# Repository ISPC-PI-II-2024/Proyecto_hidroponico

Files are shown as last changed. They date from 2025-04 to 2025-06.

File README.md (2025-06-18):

# Proyecto_hidroponico

<p align="center">
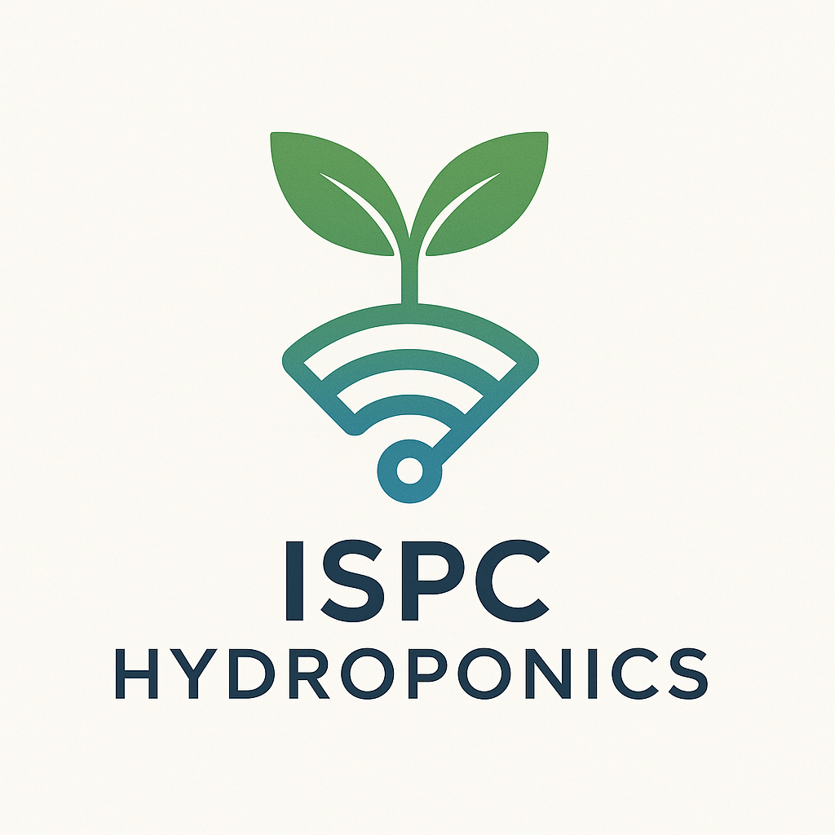
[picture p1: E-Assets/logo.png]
ISPC Hydroponics logo
  
</p>

<h1 align="center">ISPC Hydroponics</h1>

<p align="center">
  🌱 Cultivando el futuro con tecnología inteligente 💧
</p>

---

### 📌 DESCRIPCIÓN

**ISPC Hydroponics**: Este proyecto  propone el desarrollo de un sistema inteligente basado en IoT para monitorear y  automatizar variables clave en un cultivo hidropónico. Se implementa durante el primer cuatrimestre de 2024, empleando sensores, microcontroladores, protocolos  de comunicación y plataformas de visualización de datos. 
  
Es un proyecto tecnológico. Combina el diseño y programación de sistemas embebidos,  modelado de bases de datos y visualización con una investigación sobre las necesidades del cultivo hidropónico y su automatización. 

### 📌 PROBLEMÁTICA

La agricultura urbana enfrenta limitaciones en el acceso a tierra fértil y agua. Los cultivos hidropónicos requieren un control preciso de variables como pH, TDS, luz y temperatura. Se detecta la necesidad de automatizar y visualizar estos parámetros para asegurar la eficiencia del cultivo en contextos urbanos, educativos o de baja escala.

---

### 🧑‍💻 INTEGRANTES

| Nombre | GitHub |
|---|---|
| Romina Vanesa Huk | [@RoHu17](https://github.com/RoHu17) |
| Emma Vilma Gutierrez | [@emygut](https://github.com/emygut) |
| Macarena Aylèn Carballo | [@MacarenaAC](https://github.com/MacarenaAC) |
| Jose Luis Marquez | [@marquezjose](https://github.com/marquezjose) |
| Fernando Gimenez Coria | [@FerCbr](https://github.com/FerCbr) |
| Nahuel Lucas Velez | [@Lucasmurua19](https://github.com/Lucasmurua19) |
| Juan Diego Gonzalez Antoniazzi | [@JDGA1997](https://github.com/JDGA1997) |
| Lisandro Juncos Varalda | [@Lisandro-05](https://github.com/Lisandro-05) |
| Joaquin Emiliano Garzón | [@Joacogarzonn](https://github.com/Joacogarzonn) |
| Vittorio Durigutti | [@vittoriodurigutti](https://github.com/vittoriodurigutti) |
| Leandro Roldan | [@pleroldan](https://github.com/pleroldan) |
| Luciano Lujan | [@lucianoilujan](https://github.com/lucianoilujan) |
| Tiziano Paez | [@tpaez](https://github.com/tpaez) |
| Raul Jara | [@r-j28](https://github.com/r-j28) |
| Joaquin Zalazar | [@breaakerr](https://github.com/breaakerr) |
| Diego Ares | [@diegote7](https://github.com/diegote7) |
| Paola Pantoja | [@PaolaaPantoja](https://github.com/PaolaaPantoja) |

---

### EJES TEMÁTICOS/RED DE CONCEPTOS:

- Internet de las Cosas (IoT).
- Sistemas embebidos y sensores ambientales.
- Protocolos de comunicación (MQTT).
- Bases de datos y almacenamiento en la nube.
- Visualización de datos (Grafana, Node-RED).

Se busca fortalecer la capacidad de integración de tecnologías en soluciones reales, así como la habilidad para diseñar sistemas conectados y sostenibles con impacto social. 

---

### FUNDAMENTACIÓN

El proyecto fue elegido por su aplicabilidad práctica, potencial de escalabilidad y su conexión directa con la sustentabilidad alimentaria. Permite aplicar conocimientos técnicos en una solución concreta y útil, que responde tanto al perfil profesional como a una problemática global: La producción de alimentos en espacios reducidos con uso eficiente de recursos. Su impacto puede ampliarse a instituciones educativas, espacios comunitarios o pequeños productores. 

---

### STACK TECNOLÓGICO

- ESP32 + Sensores físicos
- Node-RED
- MQTT (Broker privado)
- MariaDB | Heidi-Workbench 
- Grafana
- Portainer (Orquestación Docker)
- GitHub (Scrum / Kanban)
- FAST API - Python
- VsCode + PlatformIO

---

### 📂 Organización

```
📁 /A-Requisitos                  → los requisitos del proyecto  
📁 /B-Investigacion               → Archivos de investigacion, procedimientos, apuntes, datasheets
    ┣ 📂Documentación
    ┣ 📂Información Técnica
    ┃ ┗ 📂datasheets
    ┣ 📂Integracion ..
📁 /C-Prototipos                  → Prototipos, pruebas unitarios, integraciones, etc 
    ┣ 📂Backend-APP
    ┣ 📂base de datos
    ┣ 📂Integrado V2
    ┣ 📂modelos_3D_para_imprimir
    ┣ 📂Pruebas_Unitarias
📁 /D-Presentacion                → Documentacion de presentacion, videos, diapositivas, manuales de uso
📁 /E-assets                      → Imágenes, logo, multimedia  
📄 README.md                      → Este archivo  
📄 LICENSE                        → Licencia del proyecto
```

### 🚀 Objetivos

- Monitorear variables ambientales (pH, humedad, temperatura).
- Controlar actuadores mediante Node-RED.
- Visualizar datos históricos en Grafana.
- Almacenar información en MariaDB.
- Integrar toda la arquitectura en una red Docker.
- Desarrollar e implementar una API REST para el acceso programático a los datos.

### 📂 Estructura de documentación

| Sección | Descripción |
|---|---|
| [1 - Introducción](docs/1-introduccion.md) | Presentación del proyecto y objetivos |
| [2 - Instalación](docs/2-instalacion.md) | Guía paso a paso para levantar el entorno |
| [3 - Arquitectura](docs/3-arquitectura.md) | Diagrama general del sistema IoT |
| [4 - Node-RED](docs/4-node-red.md) | Flujos de automatización y ejemplos |
| [5 - Grafana](docs/5-grafana.md) | Dashboards de visualización |
| [6 - Base de datos](docs/6-bd-mariadb.md) | Esquema de la BD y acceso |
| [8 - API REST](docs/8-api.md) | Descripción y endpoints de la API |

### 🧑‍💻 Accesos a entorno

<p align="center">
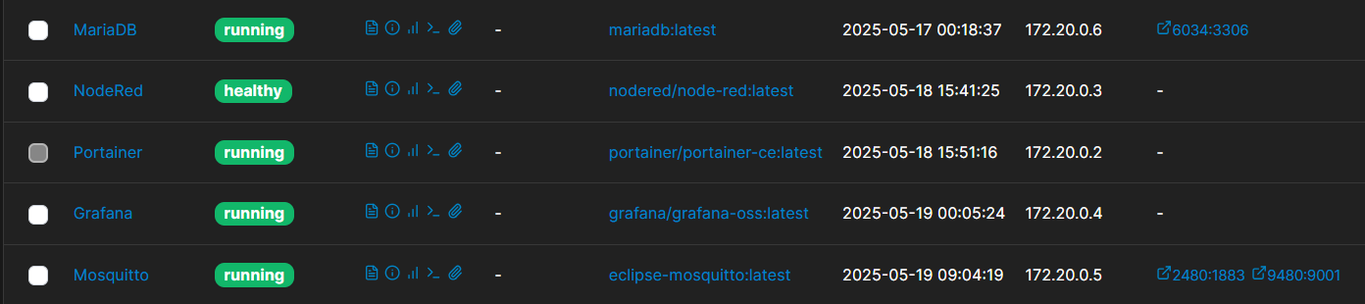
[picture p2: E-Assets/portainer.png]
Portainer logo
  
</p>

- [Node-RED](http://telecomunicaciones.ddns.net:8080/nodered/)
- [Dashboard UI](http://telecomunicaciones.ddns.net:8080/nodered/ui)
- [Grafana](http://telecomunicaciones.ddns.net:8080/grafana/)
- [Portainer](http://telecomunicaciones.ddns.net:8080/portainer/)
- [MariaDB](http://telecomunicaciones.ddns.net:6034)

> Usuario: `telecomunicaciones`  
> Contraseña: `cohorte*2024`

---

# 📘 1 - Introducción

El presente proyecto tiene como finalidad diseñar e implementar un sistema IoT para el monitoreo y control de un cultivo hidropónico. El enfoque está basado en el Aprendizaje Basado en Proyectos (ABP) integrando conocimientos adquiridos en las distintas materias del módulo FULLSTACK, correspondiente al segundo año de la tecnicatura en telecomunicaciones.

### 🧠 Justificación

- Automatización de cultivos.
- Acceso remoto a los datos.
- Toma de decisiones basada en analítica.

### 🎯 Objetivos

- Recolectar datos ambientales (humedad, pH, temperatura).
- Recolectar datos internos del sistema.
- Visualizar y analizar datos con dashboards.
- Aplicar control remoto mediante reglas automáticas, o interaccion remota y manual.
- Documentar el desarrollo siguiendo buenas prácticas de software.

---

### ⚙️ 2 - Instalación del entorno

**📦 Requisitos previos**
- Docker Desktop o Docker Engine
- Git

**🔁 Clonar el repositorio**

git clone https://github.com/ISPC-PI-II-2024/Proyecto_hidroponico.git
cd Proyecto_hidroponico

---

### 📄 3 - Arquitectura

**🧭 3 - Arquitectura del sistema**

<p align="center">
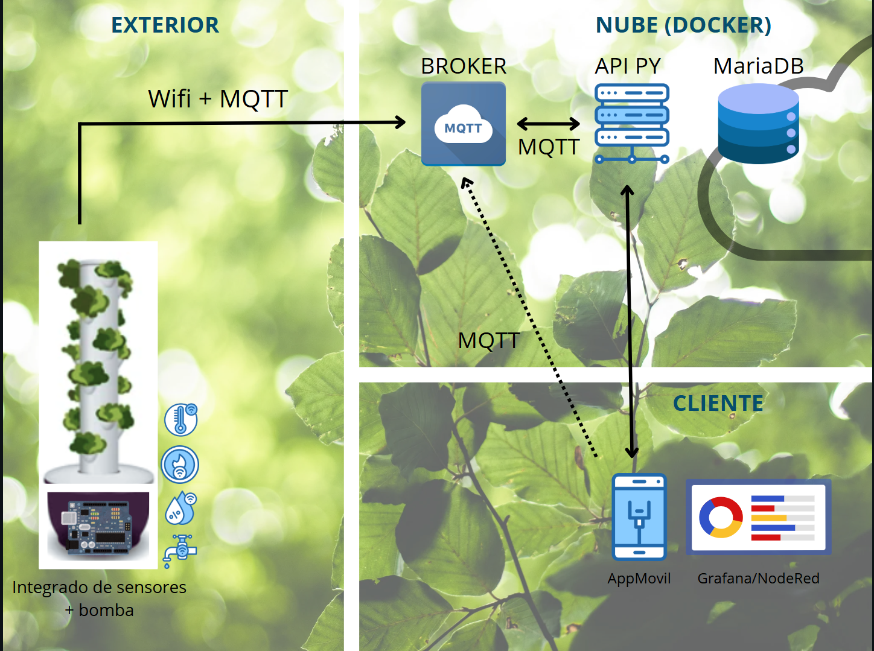
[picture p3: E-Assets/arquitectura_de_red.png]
ArquitecturaRed
  
</p>

**🔗 Descripción de componentes**

- **ESP32**: Captura datos de sensores.
- **Mosquitto**: Transmite los datos por MQTT.
- **Node-RED**: Procesa y enruta los datos.
- **MariaDB**: Almacena registros históricos.
- **Grafana**: Visualiza tendencias y análisis.

---

### 4 - Dispositivo Físico (Microcontrolador + Sistemas de sensores/actuadores)

Utilizando como cerebro del sistema un ESP32 que gestiona los sensores, actuadores y las conexiones, se disponen de un sistema extenso y complejo que nos permite leer variedad de valores del entorno, y de hasta dentro del sistema.

El mismo dispone de conexion via Wi-Fi, enviando lecturas, estado del sistemas y alarmas mediente MQTT. Toda la informacion es enviada via 2 tópicos:
- **dispositivo/info:** Este se utiliza solo al inicio/reincio del dispositivo. Está enmarcado solo dentro del setup, envía hacia la base de datos, vía broker + API el estado actual del dispositivo, indicando sensores, actuadores, las clases y los pines a los que conecta cada uno. Es sobre esta base de información, que luego se registrará cada lectura.
- **dispositivo/datos:** Este corresponde a un payload donde se envía la lectura de cada sensor, y el estado de cada actuador. El envío está programado cada 5s. Por lo que la visualización es prácticamente a tiempo real.

**Pruebas Unitarias**

- [Directorio de Pruebas unitarias](.//C-prototipos/Pruebas_Unitarias/)

A lo largo del proyecto se realizaron pruebas de cada elemento que compone el sistema, en un formato de clases, instanciado y modulado, lo cual facilitó su integración.

**Integraciones**
- [Integración: Version-1](.//C-prototipos/Integrado%20V1/)
- [Integración: Version-2](.//C-prototipos/Intregado%20V2/)

Dos formatos de integración fueron realizados. Siedo la versión 2 la que se encuentra efectivamente desplegada, y enviando datos al resto del sistema.

Dentro del directorio [Integración: Version-2] puede encontrarse información detallada del sistema, flujo de trabajo, componentes, configuración de cada elemento y manual de usuario para el menú y la interacción para con el sistema.

**Flujo de Trabajo**
```mermaid
flowchart TD
    %% Inicialización
    A[Inicio del Sistema] --> B[Inicializar Pantalla]
    B --> C[Inicializar WiFi]
    C --> D{WiFi OK?}
    D -- No --> C
    D -- Sí --> E[Conectar a MQTT Broker]
    E --> F{MQTT OK?}
    F -- No --> G[Back-off + Reintento MQTT]
    G --> E
    F -- Sí --> H[Inicializar Sensores]
    H --> I[Inicializar RTC]
    I --> J[Inicializar EEPROM]
    J --> K[Inicializar Módem GSM]
    K --> L[Entrar en Bucle Principal]
    
    %% Bucle Principal
    subgraph Bucle_Principal
      L --> M[Esperar intervaloLectura]
      M --> N[Leer Sensores]
      N --> O{mqttConectado?}
      O -- Sí --> P[Enviar datos vía MQTT]
      O -- No --> Q[Enviar datos vía GSM]
      P --> R[Actualizar Dashboard]
      Q --> R
      R --> S[Mostrar Menú/UI]
      S --> T{Interacción en Menú?}
      T -- Sí --> U[Procesar Comando Usuario]
      T -- No --> V[Continuar Bucle]
      U --> R
      V --> M
    end
```
---

## 📊 5A - Visualización con Grafana

Grafana permite construir dashboards con paneles que muestran en tiempo real o históricamente los datos del sistema hidropónico.

**🧩 Paneles incluidos**
- Temperatura del ambiente.
- Humedad del sustrato.
- Niveles de pH.
- Estado de los actuadores.
- Niveles generales de lectura de cada sensor.

**🔄 Fuentes de datos**
- MariaDB integrada como data source.

**🌐 Acceso Público:**
[CLICK AQUI](http://telecomunicaciones.ddns.net:8080/grafana/public-dashboards/855dc3a2826f476db1800452849f3251)

<p align="center">
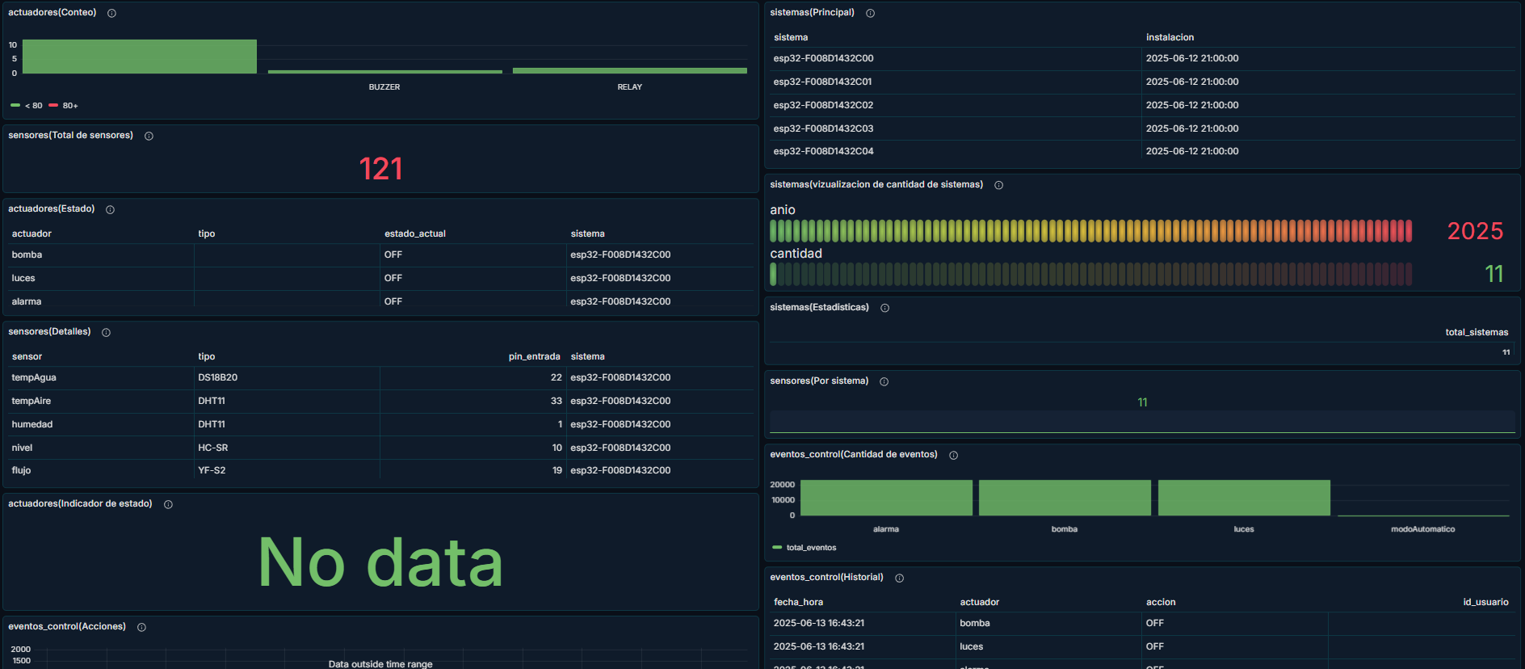
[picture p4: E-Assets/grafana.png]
Grafana
  
</p>

---

## 📊  5B - Automatización con Node-RED

Node-RED permite crear flujos lógicos para procesar, transformar y reenviar datos provenientes de sensores conectados vía MQTT.

**🔧 Funcionalidades implementadas**

- Recepción de datos desde ESP32 por MQTT.
- Filtrado y reenvío de datos a MariaDB.
- Reglas de control automático (p. ej., encendido de bombas).

**🌐 Flujos visuales:** [CLICK AQUI:](http://telecomunicaciones.ddns.net:8080/nodered/ui/#!/0?socketid=3i5QtwPpwfv6I9fGAAAq)

<p align="center">
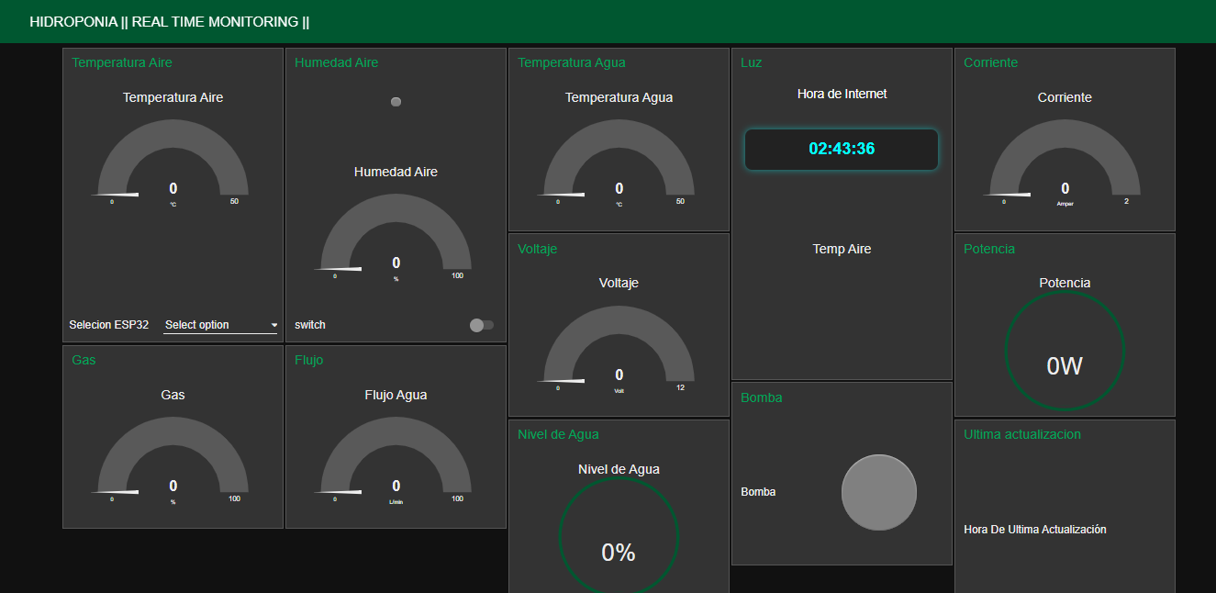
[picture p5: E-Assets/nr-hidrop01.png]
  
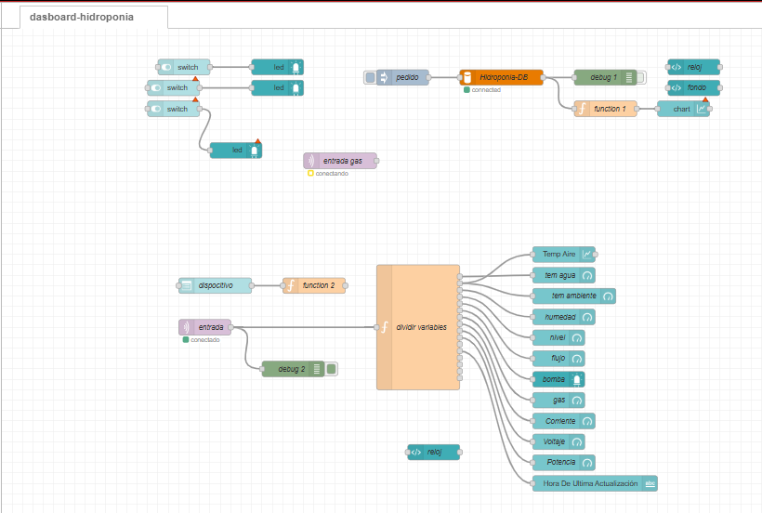
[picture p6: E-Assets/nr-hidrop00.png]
  
</p>

---
---

**🔐 Seguridad**

  #### **Los accesos a las consolas de configuracion de las aplicaciones de visualizacion como Node-RED y Grafana, montadas en el servidor privado, están protegidos con usuario y contraseña.**
  #### **Se reserva el uso solo a personal autorizado.**

---
---

## 🗃️ 6 - Base de datos MariaDB

MariaDB almacena los datos recolectados desde los sensores y enviados por Node-RED.

### 🧱 Estructura
1. **sistemas**
   - Representa cada instalación física del sistema hidropónico.
   - Un sistema puede tener múltiples sensores y actuadores.

2. **sensores**
   - Representa los sensores físicos instalados (ej: temperatura, humedad, pH).
   - Cada sensor está vinculado a un sistema y tiene un tipo, modelo, pin de entrada, etc.

3. **lecturas**
   - Almacena cada lectura generada por un sensor en una fecha y hora determinada.
   - Está directamente relacionada con un sensor.

4. **actuadores**
   - Representa los dispositivos controlables (bombas, luces, ventiladores, etc.).
   - Cada actuador está conectado a un sistema y tiene un estado actual (`ON` o `OFF`).

5. **eventos_control**
   - Registra los eventos donde un actuador fue activado o desactivado.
   - Puede incluir el nombre de la persona que realizó la acción (campo opcional `nombre_usuario`), aunque no se requiere autenticación.

6. **umbrales** 
   - Define los valores mínimos y máximos aceptables para ciertos tipos de sensores.
   - Permite generar alertas cuando una lectura está fuera de rango.

### 🔌 Conexión
- Host: `telecomunicaciones.ddns.net`
- Puerto: `6034`
- Usuario: `telecomunicaciones`
- Contraseña: `cohorte*2024`

Acceso a través de gestores como HeidiDB o MySQL Workbench, o mediante cualquier SGBD.

---

## 📡 7 - Broker MQTT (Privado, utilizando imagen de Mosquitto)

El broker MQTT se usa para recibir datos desde sensores IoT.

### 📍 Datos de conexión
- Broker: `mqtt://telecomunicaciones.ddns.net`
- Puerto: `2480` (MQTT) / `9480` (WebSocket)
- Usuario: `telecomunicaciones`
- Contraseña: `cohorte*2024`

### 📫 Topics utilizados
- `sensores/datos`
- `dispositivo/info`
- `hidroponico/control`

### 🧪 Pruebas
Podés usar MQTT Explorer para conectar y verificar los tópicos activos.
Se desarrollaron 3 aplicaciones simple que emulan datos, y envían información a los mismos tópicos a fin de afinar el parseo, registro y visualización de la información.
- [SimuladorCreacionDIspositivos.py](.//C-prototipos/Backend_APP/SimuladorCreacionDIspositivos.py)
- [SimuladorIngresoEspecifico.py](.//C-prototipos/Backend_APP/SimuladorIngresoEspecifico.py)
- [SimuladorLecturas.py](.//C-prototipos/Backend_APP/SimuladorLecturas.py)

--- 

## 🌐 8 - API REST

Se desarrolló una API tipo FastAPI, con cliente MQTT. 

### 📂 Ubicación en el repositorio
`/Backend_APP`

### 🧪 Endpoints principales
| Método | Endpoint | Descripción |
|---|---|---|
| GET | `/topic` | Obtener todas las segun el topico indicado/s en el .env |
| GET | `/message` | Obtener una lectura específica, segun el formato del mensaje |

### 🔐 Seguridad
Actualmente sin autenticación, se podrían añadir JWT o middleware de acceso en producción mas complejo o con alguna medida que sume a la seguridad.
Igualmente la API no tiene definido funciones para realizar consultas a la base de datos, únicamente para registrar cuando se cumple el formato correcto, en el topic específico.
Además, se encuentra resguardada, gracias a que el broker define para su conexion un usuario y contraseña, y un usuario de conexión creado en la DB que carece de perfil de administrador.

### 🧰 Tecnologías
- Cliente MQTT
- Docker-compose para su despliegue
- Body-parser con mapeo de datos
- Suscripción a múltiples dashboards
- Conexión a MariaDB, con healt check, y reconexión en caso de pérdida.

---

## 🌐 9 - DISEÑO 3D DE LOS MODULOS VERTICALES

Se diseñaron e imprimieron modulos utilizando tecnologia de impresion 3D, que mejorán la disposición de los actuadores, resguado del microcontrolador, y hasta disposición de las tuberías que facilitan el pase de cableado a lo lardo de la torre hidropónica.

**Diseñor y Desarrollo**
[modelos_3D_para_imprimir](.//C-prototipos/modelos_3D_para_imprimir/)

<p align="center">
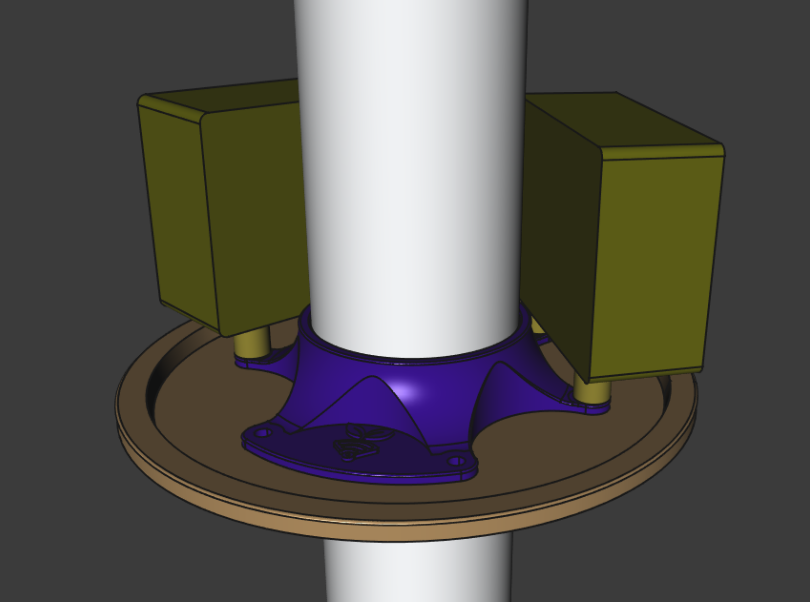
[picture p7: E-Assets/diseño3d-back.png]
Diseño 3D Back
  
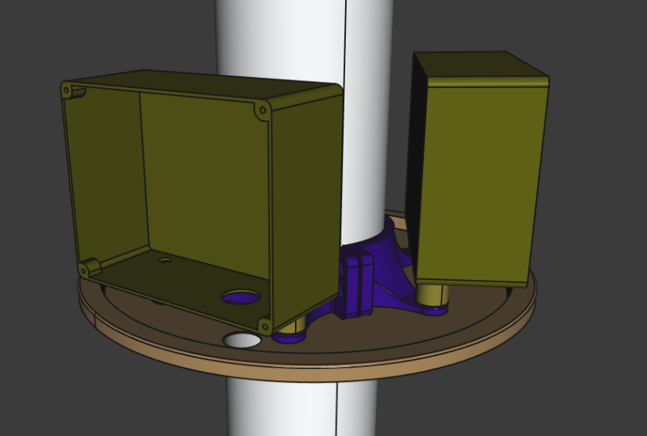
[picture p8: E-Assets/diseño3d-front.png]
Diseño 3D Front
  
</p>

---

### 📄 Licencia

Distribuido bajo la Licencia Creative Commons.

---

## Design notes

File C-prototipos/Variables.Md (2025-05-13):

# Proyecto Hidropónico: Variables y Base de Datos

Este sistema hidropónico estará integrado con **Node-RED** para la gestión de datos en tiempo real y **MariaDB** para el almacenamiento estructurado de información.
## Variables de Sensores y Control

- **`float temperaturaAgua`** → Registra la temperatura del agua en grados Celsius.
- **`float temperaturaAire`** → Mide la temperatura ambiental.
- **`float humedadAire`** → Indica la humedad relativa en el ambiente.
- **`float nivelAgua`** → Monitorea el nivel del agua en el sistema.
- **`float flujoAgua`** → Indica la velocidad de circulación del agua.
- **`int luz`** → Registra la cantidad de luz recibida por las plantas.
- **`int gas`** → Indica la concentración de gases en el ambiente.
- **`float corriente`**, **`float voltaje`**, **`float potencia`** → Variables eléctricas para el monitoreo energético.
- **`float ph`** → Mide el pH del agua para garantizar la absorción óptima de nutrientes.
- **`int lluvia`** → Indica si ha habido precipitaciones externas.
- **`int bomba`** → Estado de activación de la bomba de circulación.

## Variables de RTC (Real-Time Clock)

Para el registro preciso de datos en **MariaDB**, se incorporan variables de RTC:

- **`int año`** → Año actual.
- **`int mes`** → Mes actual.
- **`int día`** → Día actual.
- **`int hora`** → Hora actual.
- **`int minuto`** → Minuto actual.
- **`int segundo`** → Segundo actual.

## Estructura de la Base de Datos en MariaDB

### Creación de la Base de Datos y Tabla

```
CREATE DATABASE Hidroponico;
USE Hidroponico;

CREATE TABLE Sensores (
    id INT AUTO_INCREMENT PRIMARY KEY,
    temperaturaAgua FLOAT,
    temperaturaAire FLOAT,
    humedadAire FLOAT,
    nivelAgua FLOAT,
    flujoAgua FLOAT,
    luz INT,
    gas INT,
    corriente FLOAT,
    voltaje FLOAT,
    potencia FLOAT,
    ph FLOAT,
    lluvia INT,
    bomba INT,
    año INT,
    mes INT,
    día INT,
    hora INT,
    minuto INT,
    segundo INT,
    fecha_registro TIMESTAMP DEFAULT CURRENT_TIMESTAMP
);

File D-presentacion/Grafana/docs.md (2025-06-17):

# 📊 5 - Visualización con Grafana

Grafana es la herramienta utilizada para visualizar los datos recolectados por los sensores del sistema hidropónico. A través de paneles dinámicos, permite monitorear variables críticas como temperatura, humedad, y pH, facilitando el análisis y la toma de decisiones.

---

## 🔌 Conexión con MariaDB

Grafana se integra directamente con la base de datos MariaDB, donde se almacenan las lecturas enviadas desde Node-RED.

### 🔐 Datos de conexión

- **Host:** `telecomunicaciones.ddns.net`
- **Puerto:** `6034`
- **Usuario:** `telecomunicaciones`
- **Contraseña:** `cohorte*2024`
- **Base de datos:** Nombre asignado en tu contenedor 

Configuración realizada desde:  
`Connections → Data Sources → Add new → MySQL (MariaDB)`

---

## 🧩 Paneles incluidos en el Dashboard "Hidroponia"

En el dashboard actual se visualizan:

- 🌡️ **Temperatura ambiente**
- 💧 **Humedad del sustrato**
- 🧪 **Nivel de pH**

Cada panel está basado en una consulta SQL hacia la tabla `lecturas`, filtrando por tipo de sensor.

---

## 🧠 Cómo editar y entender un panel

1. Accedé a: [Dashboard Hidroponia](http://telecomunicaciones.ddns.net:8080/grafana/public-dashboards/855dc3a2826f476db1800452849f3251)
2. En cada panel, hacé clic en los tres puntos (︙) > **Edit** --> **OPCION DISPONIBLE SOLO PARA ADMINISTRADORES DEL SISTEMA**
3. Verás:
   - La **consulta SQL** al backend MariaDB
   - Tipo de visualización (línea, gauge, tabla)
   - Filtros aplicados (`$__timeFilter(timestamp)`)

### 📝 Ejemplo de consulta para temperatura

```sql
SELECT
  UNIX_TIMESTAMP(timestamp) as time_sec,
  valor as value
FROM lecturas
WHERE tipo_sensor = 'temperatura'
  AND $__timeFilter(timestamp)
ORDER BY timestamp ASC

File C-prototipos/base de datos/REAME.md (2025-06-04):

# Proyecto Hidropónico - Base de Datos

Este proyecto contiene el diseño y estructura de una base de datos relacional para el sistema hidropónico inteligente. La base de datos permite registrar sensores, lecturas, actuadores, eventos de control y sistemas instalados, siendo compatible con una interfaz tipo **dashboard** como **Node-RED** o **Grafana** para el monitoreo y control en tiempo real.

---

## Estructura de la Base de Datos

### Tablas principales:

1. **sistemas**
   - Representa cada instalación física del sistema hidropónico.
   - Un sistema puede tener múltiples sensores y actuadores.

2. **sensores**
   - Representa los sensores físicos instalados (ej: temperatura, humedad, pH).
   - Cada sensor está vinculado a un sistema y tiene un tipo, modelo, pin de entrada, etc.

3. **lecturas**
   - Almacena cada lectura generada por un sensor en una fecha y hora determinada.
   - Está directamente relacionada con un sensor.

4. **actuadores**
   - Representa los dispositivos controlables (bombas, luces, ventiladores, etc.).
   - Cada actuador está conectado a un sistema y tiene un estado actual (`ON` o `OFF`).

5. **eventos_control**
   - Registra los eventos donde un actuador fue activado o desactivado.
   - Puede incluir el nombre de la persona que realizó la acción (campo opcional `nombre_usuario`), aunque no se requiere autenticación.

6. **umbrales** 
   - Define los valores mínimos y máximos aceptables para ciertos tipos de sensores.
   - Permite generar alertas cuando una lectura está fuera de rango.

---

## 🔗 Relaciones entre tablas

```plaintext
sistemas ───< sensores ───< lecturas
        └──< actuadores ───< eventos_control

## Su Relación

### 1. **Inicio del ciclo - Lecturas desde los sensores**

- Cada **sensor** está instalado en un sistema hidropónico y está registrado en la tabla `sensores`.
- Cuando un sensor mide un dato (ej: humedad, temperatura, pH), se genera una **lectura** que se guarda en la tabla `lecturas`, junto con la **fecha**, **hora** y el **valor medido**.

> Ejemplo: el sensor de humedad `H1` toma una lectura de 35% a las 10:00 AM. Esa lectura se guarda en `lecturas` con relación directa al sensor `H1`.

---

### 2. **Visualización de datos en el dashboard**

- El sistema (por ejemplo, Node-RED o Grafana) consulta las lecturas recientes de la tabla `lecturas` para mostrar gráficos y datos en tiempo real.
- Cada sensor tiene un `tipo` (temperatura, humedad, etc.), lo cual permite agrupar y visualizar los datos adecuadamente.

---

### 3. **Análisis de condiciones - Comparación con umbrales**

- Si existe un **umbral** definido para cierto tipo de sensor (en la tabla `umbrales`), el sistema compara la lectura actual con esos valores.
- Si el valor está fuera del rango definido, se genera una alerta o se activa una lógica de control automático.

> Ejemplo: si la temperatura supera los 35 °C y el umbral máximo es 30 °C, se activa automáticamente un ventilador.

---

### 4. **Activación de actuadores (control manual o automático)**

- El sistema puede activar un **actuador** (como una bomba, luz o ventilador), el cual está registrado en la tabla `actuadores`.
- Cada actuador tiene un campo `estado_actual` (`ON` o `OFF`).
- Cuando se activa o desactiva un actuador, se registra un **evento** en la tabla `eventos_control`, que incluye la fecha, hora y, opcionalmente, el `nombre_usuario` si fue proporcionado desde el dashboard.

> Ejemplo: la bomba `B1` se enciende a las 10:05 AM. El sistema actualiza `estado_actual = 'ON'` en la tabla `actuadores`, y guarda un registro en `eventos_control` indicando qué actuador fue activado, a qué hora, y por quién si se ingresó el nombre.

---

### 5. **Acceso libre para múltiples personas**

- Hasta 20 personas pueden operar el sistema desde los dashboards sin necesidad de registrarse ni autenticarse.
- El campo `nombre_usuario` en `eventos_control` es opcional y puede usarse para dejar un registro manual de quién realizó una acción.
- No existen restricciones de acceso a nivel de base de datos, por lo que todos los operadores tienen acceso completo.

> Ejemplo: cualquier persona del equipo puede encender o apagar un actuador desde Node-RED. Si desea dejar su nombre, puede ingresarlo desde la interfaz para que se registre en la base de datos.

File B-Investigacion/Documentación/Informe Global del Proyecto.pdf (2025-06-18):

Informe Global del Proyecto: Hidroponía Inteligente para ESP32

El proyecto Hidroponia Inteligente está desarrollado sobre un ESP32 y está orientado a monitorear y controlar un sistema hidropónico de forma remota e inteligente. La arquitectura es modular, lo que permite integrar múltiples sensores, gestionar la automatización y establecer comunicación de diversas formas (WiFi + MQTT, BLE Mesh y LoRa Mesh).

Características Principales

- Sensores y Medidas
- Sensores ambientales: Temperatura y humedad (DHT11).
- Sensor de agua: Temperatura (DS18B20), nivel (ultrasónico) y flujo (caudalímetro).
- Medición adicional: Sensor de pH (con conversión básica que se puede calibrar).
- Otro: Sensor de luz (LDR), sensor de gas (MQ7) y monitorización de corriente/voltaje (INA219).
- Control y Automatización
- Gestión de riego y control de bomba.
- Control de iluminación artificial mediante un relé.
- Verificación de alarmas y notificaciones vía MQTT.
- Automatización adaptativa a partir de umbrales configurables (definidos en el módulo de control).
- Comunicaciones y Redes
- WiFi y MQTT: El ESP32 se conecta a una red WiFi y publica datos en un broker MQTT.
- BLE Mesh: Operación en red de malla a corto alcance mediante BLE.
- LoRa Mesh: Comunicación a largas distancias en redes remotas.
- Modos de Operación: Se puede configurar el nodo en modo transmisor (envía datos) o receptor (procesa y ejecuta comandos recibidos).

- Interfaz Visual y Menús
- Uso de una pantalla TFT (con Adafruit_GFX y ST7735) para mostrar información, menús interactivos y animaciones (modo standby, alertas, etc.).
- Menús para la configuración general, selección de recetas de cultivo y de red WiFi.
- Recetas de Cultivo y Configuración
- Almacenamiento en EEPROM de recetas con parámetros óptimos para diferentes cultivos (p.ej. lechuga, tomate, albahaca).
- Parámetros ajustables y calibración fina a través de archivos de configuración.
- Sincronización Horaria (RTC)
- Integración de módulos RTC (DS1307/DS3231) para mantener la hora correcta, programar eventos y registrar datos con marca temporal.

Ventajas y Escalabilidad

- Modularidad: Cada funcionalidad se encuentra en su propio módulo, lo que facilita la ampliación o modificación sin afectar el sistema global.
- Flexibilidad: Los nodos se pueden configurar como transmisores o receptores, permitiendo distintas arquitecturas de red para distribuir las tareas.
- Robustez: Los diferentes canales de comunicación (WiFi, BLE, LoRa) y el almacenamiento local (EEPROM) garantizan persistencia y adaptabilidad a diversas condiciones de red y energía.
- Diseñado para ESP32: Aprovecha la capacidad de procesamiento, conectividad WiFi/BLE y las múltiples interfaces analógicas/digitales que posee este microcontrolador.

Informe por Carpeta del Proyecto

A continuación, se describe en detalle la estructura del proyecto y los archivos que encontrarás en cada carpeta, junto con una breve descripción de sus responsabilidades.

Raíz del Proyecto

- Hidroponia.ino

Es el archivo principal que integra todos los módulos. En él se define el ciclo de trabajo (`setup()` y `loop()`), donde se inicializan la pantalla, sensores, control, comunicaciones y menús, y se coordina la lectura y envío de datos periódicamente.

- Configuración.h

Contiene definiciones y constantes globales (p.ej. velocidad de comunicación, versión del firmware) que se usan en varias partes del proyecto.

- Configuración_avanzada.h

Se establecen parámetros finos de calibración y ajustes avanzados (por ejemplo, constantes de calibración para el sensor de pH o parámetros de referencia para otros sensores).

Carpeta src/sensores

- sensores.h / sensores.cpp

Funcionalidad común para la lectura y manejo de sensores:

- Inicializa y lee datos de DHT11, DS18B20, sensor ultrasónico, caudalímetro, LDR, MQ7 y INA219.
- Proporciona variables globales para almacenar los valores medidos (temperatura del agua, temperatura ambiente, nivel de agua, flujo, etc.).
- ph_sensor.h / ph_sensor.cpp

Específico para el sensor de pH:

- Se encarga de inicializar el sensor y realizar la conversión analógica a un valor de pH, utilizando una fórmula básica que puede ser ajustada posteriormente.

Carpeta src/control

- control.h / control.cpp

Define la lógica de control:

- Establece umbrales para activar la bomba, gestionar riego y otros dispositivos.
- Incluye funciones para verificar alarmas basadas en las lecturas de los sensores y notificar eventos especiales (por ejemplo, baja del nivel de agua o pH fuera de rango).
- iluminacion.h / iluminacion.cpp

Maneja el control de un relé destinado a la iluminación artificial:

- Se definen funciones para inicializar el relé y cambiar su estado (encendido/apagado) dependiendo de las condiciones ambientales o configuraciones manuales.

Carpeta src/pantalla

- pantalla.h / pantalla.cpp

Encargado de la interfaz visual:

- Inicializa la pantalla TFT y define funciones para actualizarla, mostrar animaciones (modo standby o alertas) y renderizar información en pantalla.
- menu.h / menu.cpp

Proporciona el menú principal del sistema:

- Maneja la navegación del usuario para acceder a distintos apartados (sensores, control, recetas y configuración WiFi).
- menu_recetas.h / menu_recetas.cpp

Gestión del menú de recetas de cultivo:

- Permite la visualización, selección y edición de recetas almacenadas en EEPROM para ajustar parámetros de cultivo.

- menu_wifi.h / menu_wifi.cpp

Funcionalidades para la selección de red WiFi:

- Escanea las redes disponibles, muestra una lista en la pantalla y permite al usuario seleccionar la red a la que conectar el ESP32.

Carpeta src/comunicación

- comunicacion.h / comunicacion.cpp

Módulo central para la gestión de comunicaciones:

- Integra funciones para conectarse a WiFi, a un broker MQTT y para manejar la publicación y suscripción de mensajes.
- wifi_manager.h / wifi_manager.cpp

Gestión de las conexiones WiFi:

- Escanea redes WiFi, conecta al canal seleccionado y guarda los datos en EEPROM para la reconexión automática.
- ble_mesh.h / ble_mesh.cpp

Módulo para la comunicación mediante BLE Mesh:

- Configura un servidor BLE en el ESP32, define servicios y características para transmitir mensajes por Bluetooth en una red de malla.
- lora_mesh.h / lora_mesh.cpp

Módulo para la comunicación a larga distancia vía LoRa:

- Configura el módulo LoRa (por ejemplo, SX1278) con los pines y frecuencia adecuados, y gestiona el envío y recepción de mensajes.
- transmisor.h / transmisor.cpp

Define el modo transmisor:

- Recopila datos de los sensores y los envía (por ejemplo, vía MQTT). Se habilita o deshabilita mediante una variable (esNodoTransmisor).
- receptor.h / receptor.cpp

Define el modo receptor:

- Procesa los mensajes recibidos (por ejemplo, comandos para activar iluminación o ajustar parámetros) y ejecuta acciones en consecuencia.

Carpeta src/rtc

- rtc.h / rtc.cpp

Módulo para la gestión del reloj real (RTC):

- Inicializa el RTC, obtiene la fecha y hora actual y permite sincronizar el reloj (por ejemplo, mediante mensajes recibidos por MQTT).

Carpeta src/recetas

- recetas.h / recetas.cpp

Gestión de recetas de cultivo:

- Define la estructura `Receta` que almacena parámetros como temperatura, humedad, nivel de agua, pH e iluminación.
- Permite cargar y guardar estas recetas en EEPROM, seleccionar una receta y mostrar sus parámetros en el sistema.

Carpeta bibliotecas

- Librerías Externas

Esta carpeta se utiliza para almacenar (o referenciar) las librerías externas requeridas, tales como:

- Adafruit_GFX, Adafruit_ST7735 (para la pantalla TFT).

- PubSubClient (para MQTT).
- LoRa, BLEDevice, RTClib y EEPROM (incluida en Arduino).

La mayoría de estas librerías se instalan a través del gestor de librerías de Arduino o PlatformIO.

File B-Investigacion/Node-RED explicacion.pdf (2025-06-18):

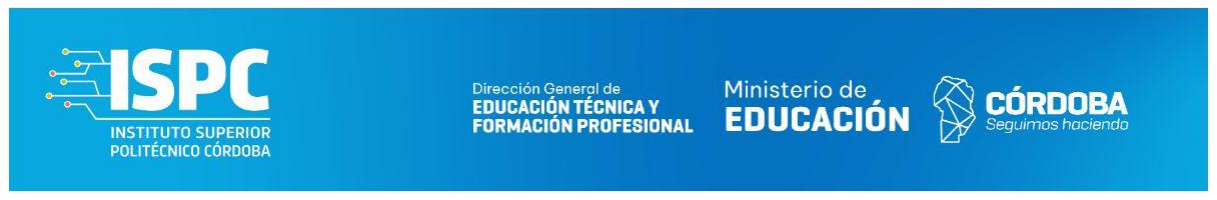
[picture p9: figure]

## NODE-RED

Node-RED es una herramienta de programación visual, de código abierto, creada para conectar dispositivos, APIs y servicios en línea de forma sencilla. Es especialmente útil para proyectos de Internet de las Cosas (IoT) y automatización, permitiendo conectar y controlar dispositivos de hardware, servicios en la nube y APIs mediante una interfaz gráfica basada en navegador.
En esencia, Node-RED permite construir aplicaciones arrastrando y conectando "nodos" que representan funciones, entradas o salidas. Estos nodos se conectan entre sí para crear flujos de trabajo que automatizan tareas, procesan datos y controlan dispositivos.

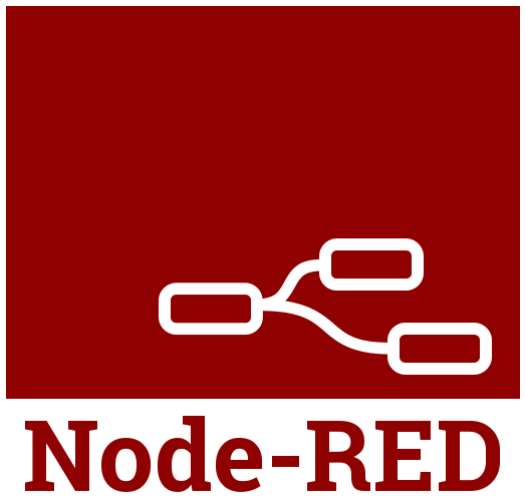
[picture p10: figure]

Características principales:
- Programación visual:
Facilita la creación de aplicaciones mediante la conexión visual de nodos, sin necesidad de escribir código complejo.
- Nodos:
Cada nodo realiza una función específica, como leer datos de un sensor, enviar un correo electrónico o controlar un actuador.
- Flujos:
Los nodos se conectan para formar flujos, que representan la secuencia de operaciones de la aplicación.

- Amplia gama de nodos:
Node-RED cuenta con una extensa librería de nodos para conectar dispositivos, servicios y APIs.
- Fácil de usar:
Es una herramienta intuitiva que permite a usuarios con diferentes niveles de experiencia construir aplicaciones.
- Código abierto:
Node-RED es gratuito y de código abierto, lo que permite su uso y adaptación a las necesidades de cada proyecto.
- Ejemplos de uso:
- Automatización del hogar: Controlar luces, termostatos y otros dispositivos inteligentes.
- Monitorización de datos: Recopilar y visualizar datos de sensores, como temperatura, humedad o consumo de energía.
- Conexión de dispositivos IoT: Integrar dispositivos como Raspberry Pi, Arduino y otros sensores en un sistema centralizado.
- Automatización industrial: Controlar maquinaria, monitorear procesos y analizar datos en tiempo real.
- Integración con servicios en la nube: Conectar con servicios como Dropbox, Google Drive, Amazon AWS y otros.
En resumen, Node-RED es una herramienta poderosa y versátil para la construcción de aplicaciones basadas en eventos, especialmente en el ámbito del IoT y la automatización, gracias a su interfaz visual, su amplia gama de nodos y su facilidad de uso.

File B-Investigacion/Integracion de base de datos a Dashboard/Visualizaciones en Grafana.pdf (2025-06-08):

# Visualizaciones en Grafana para el Sistema Hidropónia

Este documento explica la razón y utilidad de cada visualización implementada en Grafana para el monitoreo y control de sistemas hidropónicos. Cada tabla y panel está diseñado para aportar información clara y útil sobre diferentes aspectos del sistema, facilitando el análisis y la toma de decisiones.

## 1. Tabla: Sistemas

Visualización

- Panel Table

Que se puede ver?

Lista con todos los sistemas instalados, mostrando nombre y fecha de instalación.

Propósito

Permite identificar y referenciar los distintos sistemas hidropónicos registrados en la base de datos.

Uso en presentación

“Esta tabla nos da un panorama general de qué sistemas están activos y desde cuándo, lo cual es útil para tener contexto antes de analizar sensores o datos.”

## 2. Tabla: Sensores

Visualizaciones

- Panel Table: muestra nombre, tipo, pin de entrada y sistema asociado de cada sensor.
- Panel Bar chart: muestra el número de sensores por tipo (temperatura, humedad, etc.).
- Panel Bar chart o Pie chart: cantidad de sensores por sistema.

Propósito

Brinda un entendimiento completo sobre qué sensores están instalados, cómo se distribuyen por tipo y a qué sistema pertenecen.

Uso en presentación

“Con estas visualizaciones, podemos entender qué sensores hay, su distribución por tipo, y cómo están organizados en cada sistema. Esto es clave para interpretar las lecturas posteriores.”

## 3. Tabla: Lecturas

Visualizaciones

- Panel Time series: evolución temporal de los valores registrados por sensores.
- Panel Stat: muestra el valor más reciente (última lectura) de un sensor.
- Panel Table: lecturas recientes ordenadas cronológicamente.

Propósito

Monitorear los datos en tiempo real y analizar tendencias o cambios en las variables ambientales.

Uso en presentación

“Aquí vemos cómo varían las mediciones en tiempo real, lo cual nos ayuda a monitorear el estado del sistema. También mostramos la última lectura y un resumen general.”

## 4. Tabla: Actuadores

Visualizaciones

- Panel Table: lista de actuadores con tipo, estado actual, pines y sistema asociado.
- Panel Stat o Gauge: número total de actuadores activos (estado ON).
- Panel Pie chart: distribución de actuadores por tipo (bombas, luces, ventiladores, etc.).

Propósito

Permitir el control y monitoreo del estado de los dispositivos que actúan sobre el sistema.

Uso en presentación

“Aquí controlamos el estado actual de los dispositivos que actúan sobre el sistema. Podemos ver cuántos están activos y cómo están distribuidos.”

## 5. Tabla: Eventos de Control

Visualizaciones

- Panel Table: registro detallado de eventos (qué actuador fue activado/desactivado, cuándo y por qué usuario).
- Panel Bar chart: cantidad de acciones por tipo (ON/OFF).
- Panel Time series: frecuencia de eventos a lo largo del tiempo.

Propósito

Ofrecer un historial de acciones para auditoría y análisis del uso de actuadores.

Uso en presentación

“Esta tabla actúa como un historial de acciones. Nos ayuda a auditar quién activó qué actuador y con qué frecuencia.”

## 6. Tabla: Umbrales

Visualizaciones

- Panel Table: valores mínimos y máximos configurados para cada tipo de sensor.
- Panel Time series combinado con lecturas: muestra lecturas reales junto a bandas de umbral para detectar valores fuera de rango.
- Panel Stat o Bar chart: cantidad de veces que un sensor superó los umbrales establecidos.

Propósito

Detectar condiciones críticas o fallas cuando un sensor registra valores fuera del rango esperado.

Uso en presentación

“Esto permite visualizar cuándo un sensor está funcionando fuera de lo esperado. Es crucial para detectar fallos o condiciones críticas en el sistema.”

Cada visualización fue diseñada para facilitar el monitoreo, análisis y control efectivo de los sistemas hidropónicos. Juntas, proporcionan una visión integral y clara del estado actual, el historial y el desempeño general, apoyando la toma de decisiones informadas.

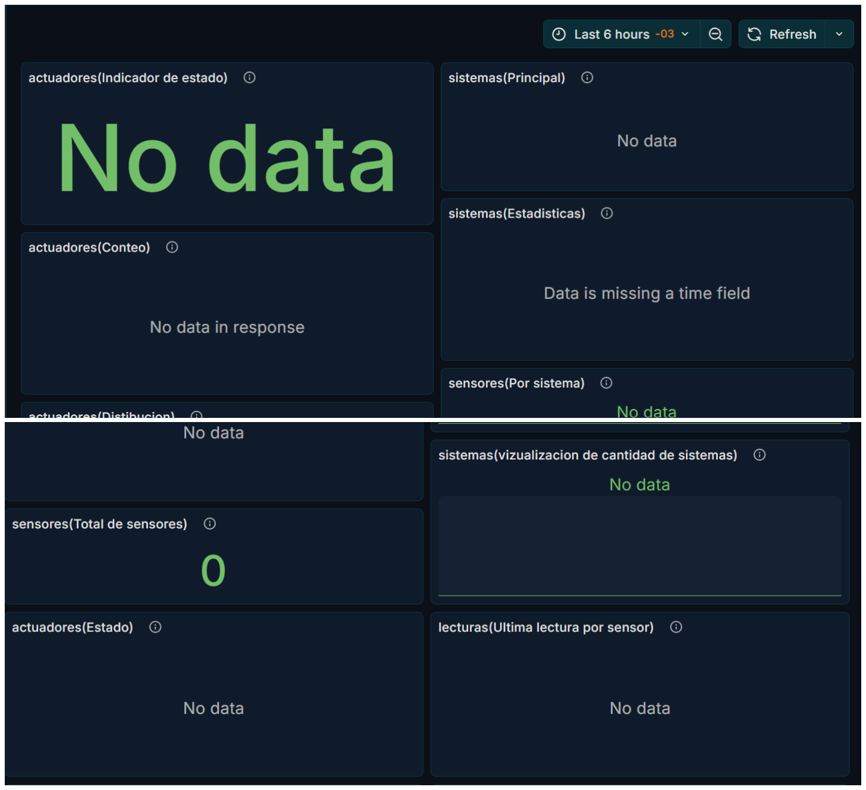
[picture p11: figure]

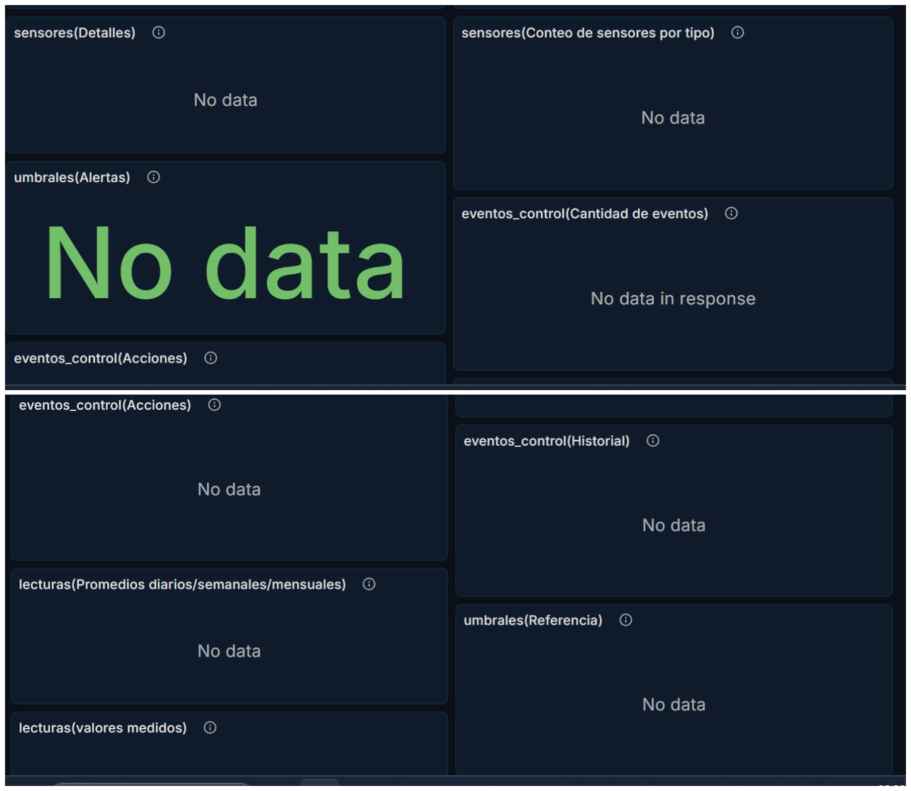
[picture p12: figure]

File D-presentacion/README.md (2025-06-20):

# Proyecto_hidroponico

<p align="center">
  ISPC Hydroponics logo
</p>

<h1 align="center">ISPC Hydroponics</h1>

<p align="center">
  🌱 Cultivando el futuro con tecnología inteligente 💧
</p>

---

## 📌 Descripción

**ISPC Hydroponics** es un proyecto IoT colaborativo desarrollado por estudiantes del Instituto Superior Politecnico Cordoba, correspondientes a la materia Proyecto Integrador 2 de la Tecnicatura Superior en Telecomunicaciones.
En el mismo se busca aplicar tecnología para monitorear y automatizar un sistema de cultivo hidropónico. 
El objetivo es construir una solución inteligente, ecológica y accesible que combine sensores, microcontroladores y visualización en tiempo real.

---

## 🧑‍💻 Integrantes

| Nombre | GitHub |
|---|---|
| Romina Vanesa Huk | [@RoHu17](https://github.com/RoHu17) |
| Emma Vilma Gutierrez | [@emygut](https://github.com/emygut) |
| Macarena Aylèn Carballo | [@MacarenaAC](https://github.com/MacarenaAC) |
| Jose Luis Marquez | [@marquezjose](https://github.com/marquezjose) |
| Fernando Gimenez Coria | [@FerCbr](https://github.com/FerCbr) |
| Nahuel Lucas Velez | [@Lucasmurua19](https://github.com/Lucasmurua19) |
| Juan Diego Gonzalez Antoniazzi  | [@JDGA1997](https://github.com/JDGA1997) |
| Lisandro Juncos Varalda | [@Lisandro-05](https://github.com/Lisandro-05) |
| Joaquin Emiliano Garzón | [@Joacogarzonn](https://github.com/Joacogarzonn) |
| Vittorio Durigutti | [@vittoriodurigutti](https://github.com/vittoriodurigutti)|
| Leandro Roldan | [@pleroldan](https://github.com/pleroldan) |
| Luciano Lujan | [@lucianoilujan](https://github.com/lucianoilujan) |
| Tiziano Paez | [@tpaez](https://github.com/tpaez) |
| Raul Jara | [@r-j28](https://github.com/r-j28) | 
| Joaquin Zalazar | [@breaakerr](https://github.com/breaakerr) |
| Diego Ares | [@diegote7](https://github.com/diegote7) |
| Paola Pantoja | [@PaolaaPantoja](https://github.com/PaolaaPantoja) |

---

## 🚀 Tecnologías

- ESP32
- Sensores de pH, EC, temperatura, humedad, luz
- MQTT / HTTP
- Node-RED / Web dashboard
- Visualización en tiempo real

---

## 📂 Organización

```
📁 /Requisitos         → los requisitos del proyecto  
📁 /Investigacion      → Archivos de investigacion, procedimientos, apuntes, datasheets 
📁 /Prototipos         → Prototipos, pruebas unitarios, integraciones, etc 
📁 /Presentacion       → Documentacion de presentacion, videos, diapositivas, manuales de uso
📁 /assets       → Imágenes, logo, multimedia  
📄 README.md     → Este archivo  
📄 LICENSE       → Licencia del proyecto
```

---

## 📄 Licencia

Distribuido bajo la Licencia Creative Commons.

---

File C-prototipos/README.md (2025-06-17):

# Proyecto_hidroponico

<p align="center">
  ISPC Hydroponics logo
</p>

<h1 align="center">ISPC Hydroponics</h1>

<p align="center">
  🌱 Cultivando el futuro con tecnología inteligente 💧
</p>

---

## 📌 Descripción

**ISPC Hydroponics** es un proyecto IoT colaborativo desarrollado por estudiantes del Instituto Superior Politecnico Cordoba, correspondientes a la materia Proyecto Integrador 2 de la Tecnicatura Superior en Telecomunicaciones.
En el mismo se busca aplicar tecnología para monitorear y automatizar un sistema de cultivo hidropónico. 
El objetivo es construir una solución inteligente, ecológica y accesible que combine sensores, microcontroladores y visualización en tiempo real.

---

## 🧑‍💻 Integrantes

| Nombre | GitHub |
|---|---|
| Romina Vanesa Huk | [@RoHu17](https://github.com/RoHu17) |
| Emma Vilma Gutierrez | [@emygut](https://github.com/emygut) |
| Macarena Aylèn Carballo | [@MacarenaAC](https://github.com/MacarenaAC) |
| Jose Luis Marquez | [@marquezjose](https://github.com/marquezjose) |
| Fernando Gimenez Coria | [@FerCbr](https://github.com/FerCbr) |
| Nahuel Lucas Velez | [@Lucasmurua19](https://github.com/Lucasmurua19) |
| Juan Diego Gonzalez Antoniazzi | [@JDGA1997](https://github.com/JDGA1997) |
| Lisandro Juncos Varalda | [@Lisandro-05](https://github.com/Lisandro-05) |
| Joaquin Emiliano Garzón | [@Joacogarzonn](https://github.com/Joacogarzonn) |
| Vittorio Durigutti | [@vittoriodurigutti](https://github.com/vittoriodurigutti) |
| Leandro Roldan | [@pleroldan](https://github.com/pleroldan) |
| Luciano Lujan | [@lucianoilujan](https://github.com/lucianoilujan) |
| Tiziano Paez | [@tpaez](https://github.com/tpaez) |
| Raul Jara | [@r-j28](https://github.com/r-j28) |
| Joaquin Zalazar | [@breaakerr](https://github.com/breaakerr) |
| Diego Ares | [@diegote7](https://github.com/diegote7) |
| Paola Pantoja | [@PaolaaPantoja](https://github.com/PaolaaPantoja) |

---

## 🧰 Tecnologías usadas

- ESP32 + sensores físicos
- Node-RED
- MQTT (Mosquitto)
- MariaDB
- Grafana
- Portainer (orquestación Docker)
- GitHub (Scrum / Kanban)
- Power BI (análisis final)
- API REST en Node.js/Express
- Visualización en tiempo real

---

## 📂 Organización

```
📁 /Requisitos         → los requisitos del proyecto  
📁 /Investigacion      → Archivos de investigacion, procedimientos, apuntes, datasheets 
📁 /Prototipos         → Prototipos, pruebas unitarios, integraciones, etc 
📁 /Presentacion       → Documentacion de presentacion, videos, diapositivas, manuales de uso
📁 /assets       → Imágenes, logo, multimedia  
📄 README.md     → Este archivo  
📄 LICENSE       → Licencia del proyecto
```

## 🚀 Objetivos

- Monitorear variables ambientales (pH, humedad, temperatura).
- Controlar actuadores mediante Node-RED.
- Visualizar datos históricos en Grafana.
- Almacenar información en MariaDB.
- Integrar toda la arquitectura en una red Docker.
- Desarrollar e implementar una API REST para el acceso programático a los datos.

## 🧰 Tecnologías usadas

## 📂 Estructura de documentación

| Sección | Descripción |
|---|---|
| [1 - Introducción](docs/1-introduccion.md) | Presentación del proyecto y objetivos |
| [2 - Instalación](docs/2-instalacion.md) | Guía paso a paso para levantar el entorno |
| [3 - Arquitectura](docs/3-arquitectura.md) | Diagrama general del sistema IoT |
| [4 - Node-RED](docs/4-node-red.md) | Flujos de automatización y ejemplos |
| [5 - Grafana](docs/5-grafana.md) | Dashboards de visualización |
| [6 - Base de datos](docs/6-bd-mariadb.md) | Esquema de la BD y acceso |
| [7 - MQTT Broker](docs/7-mqtt-broker.md) | Configuración y pruebas del broker MQTT |
| [8 - API REST](docs/8-api.md) | Descripción y endpoints de la API |

## 🧑‍💻 Accesos a entorno

- [Node-RED](http://telecomunicaciones.ddns.net:8080/nodered/)
- [Dashboard UI](http://telecomunicaciones.ddns.net:8080/nodered/ui)
- [Grafana](http://telecomunicaciones.ddns.net:8080/grafana/)
- [Portainer](http://telecomunicaciones.ddns.net:8080/portainer/)
- [MariaDB](http://telecomunicaciones.ddns.net:6034)

> Usuario: `telecomunicaciones`  
> Contraseña: `cohorte*2024`
---

# 📘 1 - Introducción

El presente proyecto tiene como finalidad diseñar e implementar un sistema IoT para el monitoreo y control de un cultivo hidropónico. El enfoque está basado en el Aprendizaje Basado en Proyectos (ABP) integrando conocimientos adquiridos en distintas materias técnicas de segundo año.

## 🧠 Justificación

- Automatización de cultivos.
- Acceso remoto a los datos.
- Toma de decisiones basada en analítica.

## 🎯 Objetivos

- Recolectar datos ambientales (humedad, pH, temperatura).
- Visualizar y analizar datos con dashboards.
- Aplicar control remoto mediante reglas automáticas.
- Documentar el desarrollo siguiendo buenas prácticas de software.
---

# ⚙️ 2 - Instalación del entorno

## 📦 Requisitos previos
- Docker Desktop o Docker Engine
- Git

## 🔁 Clonar el repositorio

git clone https://github.com/ISPC-PI-II-2024/Proyecto_hidroponico.git
cd Proyecto_hidroponico

### 📄 3 - Arquitectura

# 🧭 3 - Arquitectura del sistema

## 🌐 Diagrama general

## 🔗 Descripción de componentes

- **ESP32**: Captura datos de sensores.
- **Mosquitto**: Transmite los datos por MQTT.
- **Node-RED**: Procesa y enruta los datos.
- **MariaDB**: Almacena registros históricos.
- **Grafana**: Visualiza tendencias y análisis.
---

# 🔄 4 - Automatización con Node-RED

Node-RED permite crear flujos lógicos para procesar, transformar y reenviar datos provenientes de sensores conectados vía MQTT.

## 🔧 Funcionalidades implementadas

- Recepción de datos desde ESP32 por MQTT.
- Filtrado y reenvío de datos a MariaDB.
- Reglas de control automático (p. ej., encendido de bombas).

## 🌐 Flujos visuales

(Sugerencia: insertar aquí una imagen del flujo Node-RED o exportar como JSON y documentarlo)

## 🔐 Seguridad

El acceso a Node-RED está protegido con usuario y contraseña.
---

# 📊 5 - Visualización con Grafana

Grafana permite construir dashboards con paneles que muestran en tiempo real o históricamente los datos del sistema hidropónico.

## 🧩 Paneles incluidos
- Temperatura del ambiente.
- Humedad del sustrato.
- Niveles de pH.

## 🔄 Fuentes de datos
- MariaDB integrada como data source.

## 🌐 Acceso
http://telecomunicaciones.ddns.net:8080/grafana/

http://telecomunicaciones.ddns.net:8080/grafana/
---

# 🗃️ 6 - Base de datos MariaDB

MariaDB almacena los datos recolectados desde los sensores y enviados por Node-RED.

## 🧱 Estructura
- `lecturas` (id, tipo_sensor, valor, timestamp)
- `alertas` (id, tipo, descripcion, timestamp)

## 🔌 Conexión
- Host: `telecomunicaciones.ddns.net`
- Puerto: `6034`
- Usuario: `telecomunicaciones`
- Contraseña: `cohorte*2024`

Acceso a través de gestores como MariaDB o MySQL Workbench.
---

# 📡 7 - Broker MQTT (Mosquitto)

El broker MQTT se usa para recibir datos desde sensores IoT.

## 📍 Datos de conexión
- Broker: `mqtt://telecomunicaciones.ddns.net`
- Puerto: `2480` (MQTT) / `9480` (WebSocket)
- Usuario: `telecomunicaciones`
- Contraseña: `cohorte*2024`

## 📫 Topics utilizados
- `hidroponico/temperatura`
- `hidroponico/humedad`
- `hidroponico/ph`

## 🧪 Pruebas
Podés usar MQTT Explorer para conectar y verificar los tópicos activos.
--- 

# 🌐 8 - API REST

Se desarrolló una API RESTful en Node.js utilizando Express para acceder a los datos del sistema.

## 📂 Ubicación en el repositorio
`/api`

## 🧪 Endpoints principales
| Método | Endpoint | Descripción |
|---|---|---|
| GET | `/api/lecturas` | Obtener todas las lecturas |
| GET | `/api/lecturas/:id` | Obtener una lectura específica |
| POST | `/api/lecturas` | Agregar una nueva lectura |
| DELETE | `/api/lecturas/:id` | Eliminar una lectura |

## 🔐 Seguridad
Actualmente sin autenticación, se recomienda añadir JWT o middleware de acceso en producción.

## 🧰 Tecnologías
- Node.js
- Express
- Body-parser
- Conexión a MariaDB
---

## 📄 Licencia

Distribuido bajo la Licencia Creative Commons.

---

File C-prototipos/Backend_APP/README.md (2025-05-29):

## API 01

### Procesamiento de Informacion y Registro en BD

Esta API funcionara como el nodo conector entre el dispositivo fisico y las Bases de datos.
Purgara la informacion, y ordenara, y posteriormente registrara en los formatos adecuador para poder reflejar los datos de manera informativa, y en tiempo real. 
La misma escuchara de forma pasiva los mensajes presnetes en los topicos en que los dispositivos registren sus lecturas, corriendo en un contenedor Docker, conectado a la red donde se desplegaran asi mismo la base de datos en MariaDB

---

### Estructura del Directorio

- 📦Backend
-  ┣ 📂app                          // Directorio principal de la aplicacion
-  ┃ ┣ 📂api                        // Elementos de inico de la AIP y gestion de routas [host/api]
-  ┃ ┃ ┣ 📜routes.py                // Gestor de rutas definidas en la aplicacion
-  ┃ ┃ ┗ 📜__init__.py              // Elemento importador de los endpoind del directorio 
-  ┃ ┣ 📂models                     // Elementos asociado a modelos predefinidos, de momento solo estructura de los mensajes recividos
-  ┃ ┃ ┗ 📜mensaje.py               // Estructurador de formato de los mensjaes
-  ┃ ┣ 📂services                   // Estructura la conexion con los diferentes servicios a los que conecta la API
-  ┃ ┃ ┗ 📜maria_serv.py            // Estructura conexion con la base de datos en MySQL
-  ┃ ┣ 📂utils
-  ┃ ┃ ┗ 📜logger.py                // Gestiona los logs del sistema, asi como la categorizacion de los mismos
-  ┃ ┣ 📜config.py                  // Configuracion de la aplicacion y sus endpoints. Estps son llamados del .env
-  ┃ ┣ 📜main.py                    // Cuerpo de la aplicacion. Inicio, gestion del listener, del healtcheck, y ruta principal  
-  ┃ ┣ 📜mqtt_listener.py           // Listener en segundo plano de las conexiones y topicos MQTT
-  ┃ ┗ 📜__init__.py
-  ┣ 📜.env                         // Documento de enviroment donde se definen los valores finales antes de desplegar
-  ┣ 📜docker-compose.yml           // Docke-compose para creacion y parametros del contenedor
-  ┣ 📜Dockerfile
-  ┣ 📜README.md
-  ┗ 📜requirements.txt             // Librerias/instalaciones que deben ejecutarse en la imagen del contenedor

---

### Instacion solicitadas en el "requirements.txt"
- fastapi
    - Framework web asíncrono sobre el que montamos nuestros endpoints y el ciclo de vida de la app.
- uvicorn[standard]
    - Servidor ASGI ligero para ejecutar FastAPI, con extras ([standard]) como watchdog para recarga en caliente.
- paho-mqtt
    - Cliente MQTT para suscribirte a topics y procesar mensajes.
- mysql-connector-python
    - Driver oficial de Oracle para conectar a MySQL desde Python.
- python-dotenv
    - (Opcional si tu editor o entorno no carga .env automáticamente) permite que Pydantic BaseSettings lea tu .env.
- sqlalchemy
    - ORM/kit de conexión SQL que te facilitará abstraer consultas y gestión de sesiones en MySQL.

---

### Flujo de Datos

```mermaid
flowchart LR
  %% Dispositivo que envía mensajes al broker MQTT
  Dispositivo[Dispositivo]

  %% MQTT subsystem
  subgraph MQTT_Listener
    direction TB
    Broker[MQTT Broker]
    Listener["MQTTListener
(on_message)"]
  end

  %% Persistence services
  subgraph Persistence
    direction TB
    MySQLService[MySQL Service]
    MySQLDB[(MySQL DB)]
  end

  %% HTTP API
  subgraph HTTP_API
    direction TB
    Client["API Client
(e.g. dashboard)"]
    FastAPI[FastAPI App]
    Router[/api router/]
    Health[/GET /health/]
    Topics[/GET /api/topics/]
    Messages[/GET /api/messages/]
  end

  %% Connections
  Dispositivo --> Broker
  Broker --> Listener
  Listener -->|payload JSON| MySQLService
  MySQLService --> MySQLDB

  Client --> FastAPI
  FastAPI --> Health
  FastAPI --> Router
  Router --> Topics
  Router --> Messages
  Messages -->|consulta| MySQLService

```

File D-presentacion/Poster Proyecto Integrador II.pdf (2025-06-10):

Tecnológico

Proyecto IntegradorII

Internet de las Cosas (IoT).
Sistemas embebidos y sensores ambientales. Protocolos de comunicación (MQTT).
Bases de datos y almacenamiento en la nube. Visualización de datos (Grafana, Node-RED).
Se busca fortalecerla capacidad de integración de tecnologías en soluciones reales, así como la habilidad para diseñar sistemas conectados y sostenibles con impacto social.

La agricultura urbana enfrenta limitaciones en el acceso a tierra fértil y agua. Los cultivos hidropónicos requieren un control preciso de variables como pH, TDS, luz y temperatura. Se detecta la necesidad de automatizar y visualizar estos parámetros para asegurar la eficiencia del cultivo en contextos urbanos, educativos o de baja escala.

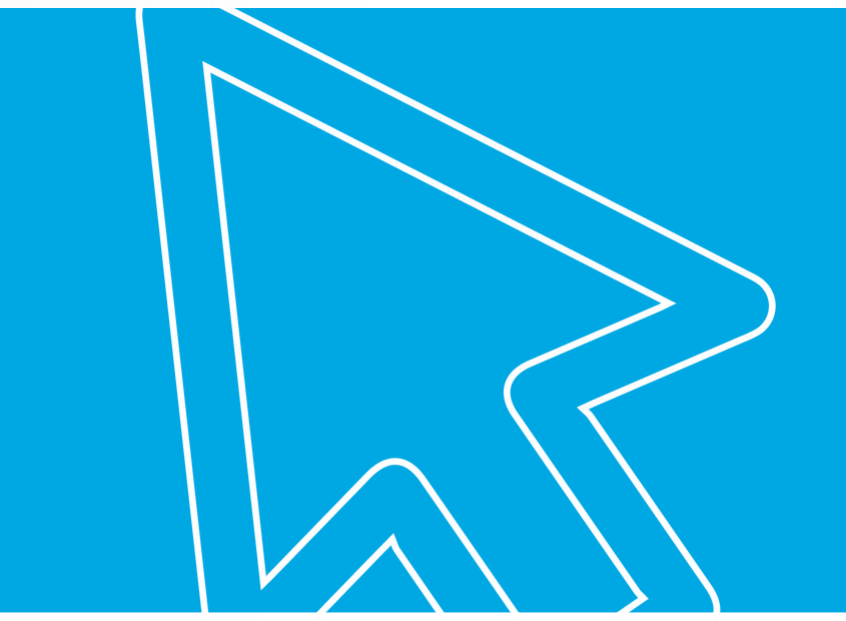
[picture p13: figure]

Desarrollar un sistema inteligente de monitoreo y automatización para cultivo hidropónico que permite controlar variables ambientales críticas y visualizar datos en tiempo real.

Integrar sensores de pH, TDS,temperatura, luz y caudal en una única plataforma. Establecer comunicación eficiente mediante MQTT y registrar datos en una base de datos relacional.
Crear dashboards funcionales en Grafana y Node-RED.
Automatizar el accionamiento de bombas y relés según umbrales definidos.

# ISPC HIDROPONICS

El proyecto fue elegido por su aplicabilidad práctica, potencial de escalabilidad y su conexión directa con la sustentabilidad alimentaria. Permite aplicar conocimientos técnicos en una solución concreta y útil, que responde tanto al perfil profesional como a una problemática global: la producción de alimentos en espacios reducidos con uso eficiente de recursos. Su impacto puede ampliarse a instituciones educativas, espacios comunitarios o pequeños productores.

TIPO DE PROYECTO:

ESPACIO CURRICULAR/MÓDULO:

EJE TEMÁTICO/RED DE CONCEPTOS:

PROBLEMÁTICAS/NECESIDADES:

FUNDAMENTACIÓN:

El producto final consiste en un sistema de cultivo hidropónico con monitoreo ambiental automatizado y visualización de datos en tiempo real. Este sistema integra sensores, microcontroladores, bases de datos y dashboards funcionales, y puede ser aplicado tanto en entornos educativos como comunitarios.
Además, se generará documentación técnica que puede compartirse con otras instituciones o en redes para difundir el valor de los cultivos hidropónicos inteligentes. Para más información ingrese al Repositorio Proyecto Hidropónico. https://github.com/ISPC-PI-II-2024/Proyecto_hidroponico.

PRODUCTO FINAL:

OBJETIVO GENERAL:

OBJETIVO ESPECÍFICO:

INTEGRANTES:
TECNICATURA:

COHORTE: DOCENTE:

Fernando Gimenez Coria
Diego Ares
Macarena Carballo
Lisandro Juncos
Vittorio Durigutti
Luciano Lujan
Jose Luis Marquez
Juan Diego Gonzalez Antoniazzi

Superior en Telecomunicaciones

2024 Mario Gonzalez

- Selección y prueba de sensores.
- Conexión física y validación individual.
- Codificación para lectura de datos.
- Configuración del broker MQTT.
- Programación de envío de datos.
- Creación y prueba de base de datos MySQL.
- Almacenamiento automático de lecturas. -Instalación de Grafana y Node-RED.
- Configuración de entradas desde base de datos.
- Diseño de paneles visuales para cada variable.
- Codificación de lógica de control.
- Conexión y prueba de relé y bomba.
- Implementación de condiciones automatizadas.

ACCIONES:

### Objetivo 1

### Objetivo 2

### Objetivo 3

### Objetivo 4

Joaquin Zalazar
Tiziano Paez
Leandro Roldan
Nahuel Velez
Paola Pantoja
Romina Huk
Emma Gutierrez
Raul Jara

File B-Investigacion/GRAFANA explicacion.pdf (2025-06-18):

## GRAFANA

Grafana es una plataforma de código abierto, principalmente usada para la visualización y análisis de datos métricos. Permite crear dashboards personalizados y dinámicos para monitorear infraestructuras y aplicaciones IT. Se conecta a diversas fuentes de datos para mostrar información en gráficos e informes visualmente atractivos.
- Visualización de datos:
Grafana se destaca por su capacidad para transformar datos en visualizaciones claras y concisas, facilitando la comprensión de la información.
- Paneles de control personalizados:
Los usuarios pueden diseñar sus propios paneles de control, adaptados a sus necesidades específicas, mostrando métricas relevantes de diferentes fuentes.
- Integración con múltiples fuentes de datos:
Grafana es compatible con una amplia gama de fuentes de datos, como bases de datos, sistemas de monitoreo y servicios en la nube, lo que la convierte en una herramienta versátil.
- Análisis en tiempo real:
Permite monitorear datos en tiempo real y detectar patrones y tendencias, lo que es crucial para la toma de decisiones informadas.
- Código abierto:
Al ser de código abierto, Grafana se beneficia de una comunidad activa y actualizaciones constantes, además de ofrecer flexibilidad y personalización.
- Casos de uso:
Grafana se utiliza en diversos escenarios, desde el monitoreo de sistemas IT hasta el análisis de datos IoT y el seguimiento de rendimiento de aplicaciones.
En resumen, Grafana es una herramienta poderosa para la visualización y análisis de datos que ayuda a empresas y organizaciones a comprender mejor su información y tomar decisiones basadas en datos.

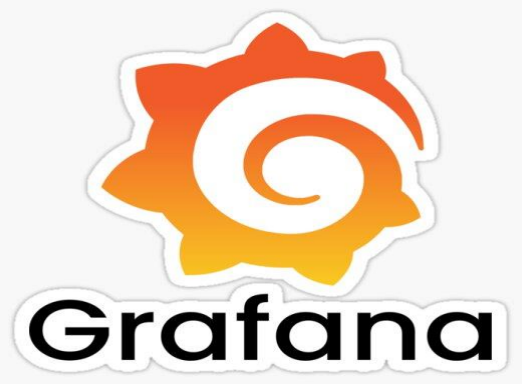
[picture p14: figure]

Pasos básicos para usar Grafana:
1. Instalación y acceso:
Grafana se puede instalar en diferentes sistemas operativos, como Linux y Windows. También se puede acceder a través de servicios en la nube.
Una vez instalado, se accede a la interfaz web a través de un navegador.
La dirección web típica es http://[tu_servidor]:3000.
El usuario y contraseña por defecto suelen ser admin/admin.
Se recomienda cambiar la contraseña de administrador después del primer inicio de sesión.
2. Configuración de fuentes de datos:
Grafana se conecta a diversas fuentes de datos, como bases de datos (PostgreSQL, MySQL), sistemas de monitoreo (Prometheus, Graphite) y servicios en la nube (AWS CloudWatch, Azure Monitor).
Se deben agregar y configurar estas fuentes de datos en Grafana para poder acceder a los datos.
La configuración incluye información como la URL, credenciales de acceso y tipo de base de datos.

3. Creación de dashboards:
Los dashboards son el espacio donde se visualizan los datos.
Se pueden crear dashboards desde cero o importar plantillas.
Se pueden agregar paneles (paneles gráficos, tablas, mapas, etc.) a los dashboards. Cada panel se configura para mostrar datos específicos de una fuente de datos.
Se pueden usar expresiones y funciones para manipular los datos dentro de los paneles.
4. Configuración de alertas:
Grafana permite configurar alertas que se activan cuando ciertas condiciones se cumplen.
Las alertas se pueden configurar para que envíen notificaciones a través de diferentes canales (correo electrónico, Slack, etc.).
Esto permite monitorear el estado de los sistemas y recibir notificaciones en caso de problemas.
Ejemplo de uso:
- Se puede utilizar Grafana para visualizar el rendimiento de un servidor web, mostrando métricas como el número de peticiones, el tiempo de respuesta y el tráfico.
- Se pueden crear paneles que muestren el uso de CPU, memoria y disco del servidor.
- Se pueden configurar alertas para notificar si el uso de CPU supera un cierto umbral.

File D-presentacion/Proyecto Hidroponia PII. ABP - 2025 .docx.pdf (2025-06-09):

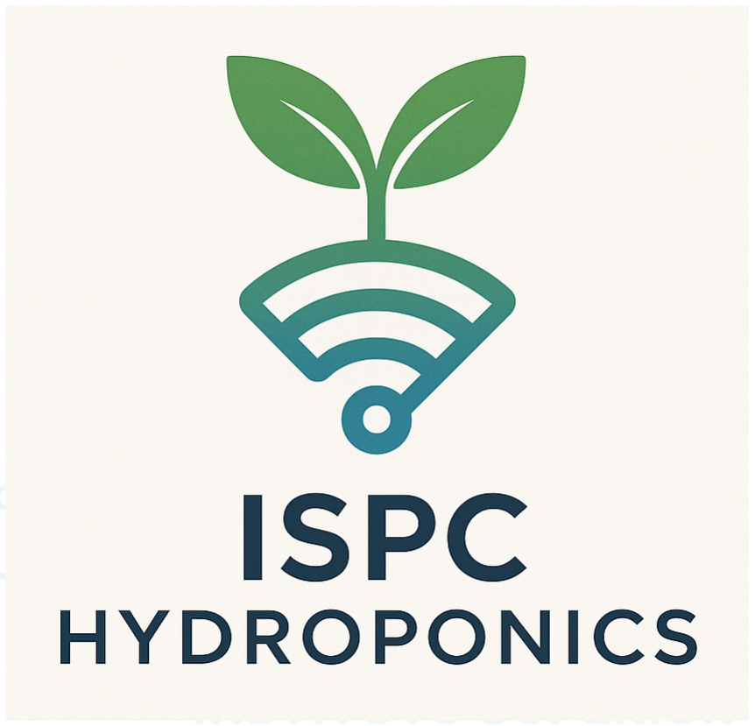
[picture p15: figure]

Cultivando el futuro con tecnología inteligente

Integrantes:

- Romina Huk | - Emma Gutierrez
- Jose Luis Marquez | - Fernando Gimenez Coria
- Juan Diego Gonzalez Antoniazzi - Lisandro Juncos
- Diego Ares | - Vittorio Durigutti
- Leandro Roldan | - Nahuel Velez
- Macarena Carballo | - Luciano Lujan
- Tiziano Paez | - Raul Jara
- Joaquin Zalazar | - Paola Pantoja

### 1. NOMBRE DEL PROYECTO:

“Sistema de Monitoreo y Automatización para Cultivo Hidropónico”. Este proyecto propone el desarrollo de un sistema inteligente basado en IoT para monitorear y automatizar variables clave en un cultivo hidropónico. Se implementa durante el primer cuatrimestre de 2024, empleando sensores, microcontroladores, protocolos de comunicación y plataformas de visualización de datos.

### 2. TIPO DE PROYECTO:

Proyecto tecnológico. Combina el diseño y programación de sistemas embebidos, modelado de bases de datos y visualización con una investigación sobre las necesidades del cultivo hidropónico y su automatización.

### 3. ESPACIO CURRICULAR O ESPACIOS PARTICIPANTES EN EL MÓDULO:

Modulo Proyecto Integrador II. - Prof. Mario Gonzalez.

### 4. EJES TEMÁTICOS/RED DE CONCEPTOS:

- Internet de las Cosas (IoT).
- Sistemas embebidos y sensores ambientales.
- Protocolos de comunicación (MQTT).
- Bases de datos y almacenamiento en la nube.
- Visualización de datos (Grafana, Node-RED).
Se busca fortalecer la capacidad de integración de tecnologías en soluciones reales, así como la habilidad para diseñar sistemas conectados y sostenibles con impacto social.

### 5. PROBLEMÁTICAS/NECESIDADES:

La agricultura urbana enfrenta limitaciones en el acceso a tierra fértil y agua. Los cultivos hidropónicos requieren un control preciso de variables como pH, TDS, luz y temperatura. Se detecta la necesidad de automatizar y visualizar estos parámetros para asegurar la eficiencia del cultivo en contextos urbanos, educativos o de baja escala.

### 6. FUNDAMENTACIÓN:

El proyecto fue elegido por su aplicabilidad práctica, potencial de escalabilidad y su conexión directa con la sustentabilidad alimentaria. Permite aplicar conocimientos técnicos en una solución concreta y útil, que responde tanto al perfil profesional como a una problemática global: la producción de alimentos en espacios reducidos con uso eficiente de recursos. Su impacto puede ampliarse a instituciones educativas, espacios comunitarios o pequeños productores.

### 7. VISIÓN DEL PROYECTO:

Aspiramos a consolidar un sistema modular, adaptable a distintas escalas y tipos de cultivo, que pueda ser implementado tanto en simuladores como en hardware real. Se visualiza como una herramienta de aprendizaje tecnológico y también de solución productiva.

DISEÑO DE LOS OBJETIVOS

- Objetivo general: Desarrollar un sistema inteligente de monitoreo y automatización para cultivo hidropónico que permite controlar variables ambientales críticas y visualizar datos en tiempo real.
- Objetivos específicos:
- Integrar sensores de pH, TDS, temperatura, luz y caudal en una única plataforma.
- Establecer comunicación eficiente mediante MQTT y registrar datos en una base de datos relacional.
- Crear dashboards funcionales en Grafana y Node-RED.
- Automatizar el accionamiento de bombas y relés según umbrales definidos.
- Metas:
- Prototipo funcional en entorno simulado (Wokwi) y pruebas en hardware real.
- Dashboard operando con datos en tiempo real.
- Documentación completa del proceso y código.

- Informe final validado y presentado en instancia académica.

### 8. SELECCIÓN DE ACCIONES

OBJETIVO ESPECÍFICO | ACCIONES
Integrar sensores de pH, TDS, temperatura, luz y caudal en una única plataforma. | - Selección y prueba de sensores. - Conexión física y validación individual. - Codificación para lectura de datos.
Establecer comunicación eficiente mediante MQTT y registrar datos en una base de datos relacional. | - Configuración del broker MQTT. - Programación de envío de datos. - Creación y prueba de base de datos MySQL. - Almacenamiento automático de lecturas.
Crear dashboards funcionales en Grafana y Node-RED. | - Instalación de Grafana y Node-RED. - Configuración de entradas desde base de datos. - Diseño de paneles visuales para cada variable.
Automatizar el accionamiento de bombas y relés según umbrales definidos | - Codificación de lógica de control. - Conexión y prueba de relé y bomba. - Implementación de condiciones automatizadas.

### 9. CRONOGRAMA:

CRONOGRAMA | SEMANA 1 | SEMANA 2 | SEMANA 3 | SEMANA 4
Objetivo 1: Integrar sensores | Selección de sensores. | Conexión física. | Codificación básica. | Pruebas unitarias.
Objetivo 2: MQTT y base de datos | Configuración MQTT. | Pruebas de envío. | Diseño de BD. | Enlace sensor-BD.
Objetivo 3: Dashboards | Instalación de software. | Diseño de paneles. | Integración de datos. | Integración de datos.
Objetivo 4: Automatización | Conexión relés/bombas | Codificación lógica. | Testeo de umbrales. | Integración total.

10.PRODUCTO FINAL:

El producto final consiste en un sistema de cultivo hidropónico con monitoreo ambiental automatizado y visualización de datos en tiempo real. Este sistema integra sensores, microcontroladores, bases de datos y dashboards funcionales, y puede ser aplicado tanto en entornos educativos como comunitarios.

Además, se generará documentación técnica que puede compartirse con otras instituciones o en redes para difundir el valor de los cultivos hidropónicos inteligentes. Para más información ingrese al Repositorio Proyecto Hidropónico. https://github.com/ISPC-PI-II-2024/Proyecto_hidroponico.

### 11. BIBLIOGRAFÍA

- Arduino. (s.f.). Documentación oficial. https://www.arduino.cc/
- Grafana Labs. (s.f.). Visualize anything with Grafana. https://grafana.com/
- Node-RED. (s.f.). Flow-based programming for the Internet of Things. https://nodered.org/
- ISPC | GitHub. | (2024). | Repositorio | Proyecto | Hidropónico.
https://github.com/ISPC-PI-II-2024/Proyecto_hidroponico
- American Psychological Association. (2020). Publication manual of the American Psychological Association (7th ed.).

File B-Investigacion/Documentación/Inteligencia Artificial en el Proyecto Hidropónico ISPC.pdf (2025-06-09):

¿Cómo Aplicar Inteligencia Artificial en el Proyecto Hidropónico ISPC?

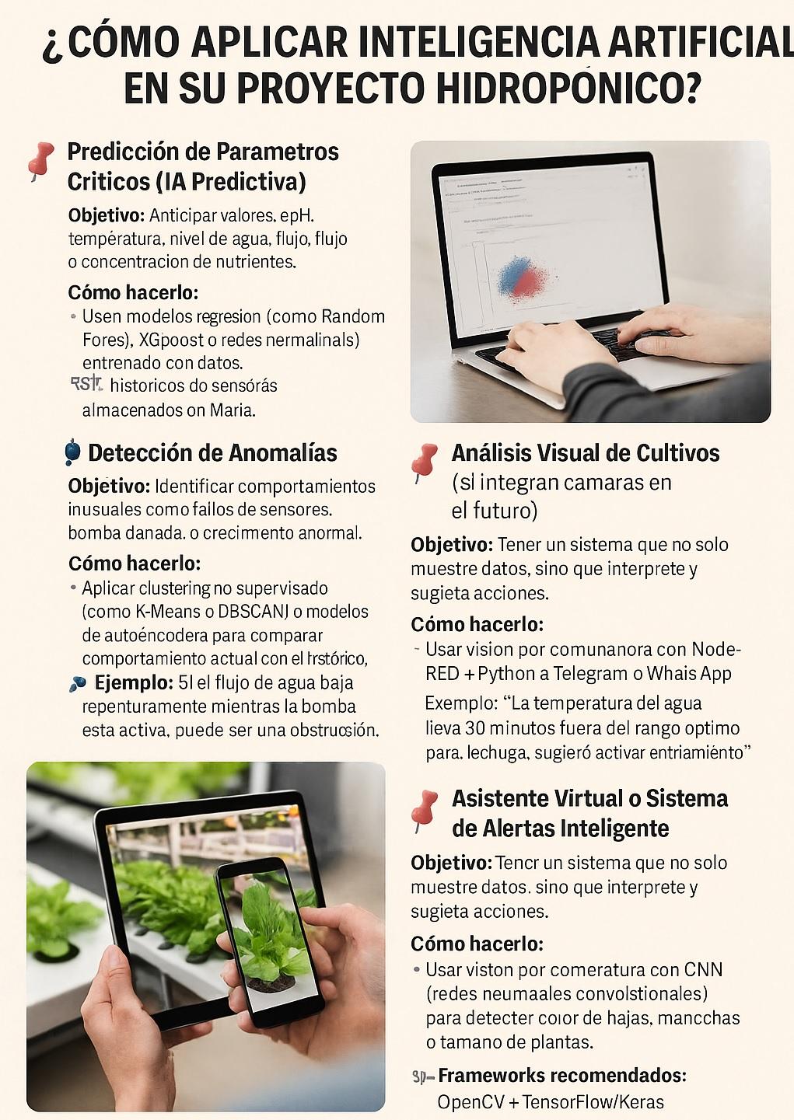
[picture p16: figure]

### 1. Predicción de Parámetros Críticos (IA Predictiva)

Objetivo: Anticipar valores de pH, temperatura, nivel de agua, flujo o concentración de nutrientes.

Cómo hacerlo:

- Usen modelos de regresión (como Random Forest, XGBoost o redes neuronales) entrenados con datos históricos de sensores almacenados en MariaDB.
- Predecir cuándo habrá que ajustar nutrientes, encender bomba o controlar luz.

Tecnologías: Python (scikit-learn, TensorFlow), Jupyter Notebook conectado a la base MariaDB.

### 2. Detección de Anomalías

Objetivo: Identificar comportamientos inusuales como fallos de sensores, bomba dañada, o crecimiento anormal.

Cómo hacerlo:

- Aplicar clustering no supervisado (como K-Means o DBSCAN) o modelos de autoencoders para comparar comportamiento actual con el histórico.

Ejemplo: Si el flujo de agua baja repentinamente mientras la bomba está activa, puede ser una obstrucción.

### 3. Optimización de Recursos mediante IA (Recomendación)

Objetivo: Ajustar automáticamente iluminación, riego o nutrientes para maximizar rendimiento.

Cómo hacerlo:

Aplicar técnicas de optimización como algoritmos genéticos o reinforcement learning que, con base en las condiciones del cultivo y resultados anteriores, propongan configuraciones óptimas.

Ejemplo: Encender luces solo cuando la intensidad de luz natural sea menor a 200 lux y el crecimiento haya sido deficiente.

### 4. Análisis Visual de Cultivos (si se integran cámaras en el futuro)

Objetivo: Detectar deficiencias nutricionales, plagas o crecimiento deficiente usando imágenes.

Cómo hacerlo:

- Usar visión por computadora con CNN (redes neuronales convolucionales) para detectar color de hojas, manchas o tamaño de plantas.

Frameworks recomendados: OpenCV + TensorFlow/Keras.

### 5. Asistente Virtual o Sistema de Alertas Inteligente

Objetivo: Tener un sistema que no solo muestre datos, sino que interprete y sugiera acciones.

Cómo hacerlo:

- Programar reglas inteligentes basadas en IA con Node-RED + Python + Telegram o WhatsApp bot.
- Ejemplo: “La temperatura del agua lleva 30 minutos fuera del rango óptimo para lechuga, sugiero activar enfriamiento.”

¿Por Dónde Empezar?

1. Recolectar más datos históricos en MariaDB (mínimo 1 mes continuo).
2. Exportar los datos a CSV y entrenar modelos simples en Python.
3. Probar un modelo de regresión simple para predecir pH o TDS.
4. Integrar el modelo con Node-RED usando node-red-node-python o vía HTTP API.

¿Cómo visualizar IA en Node-RED + Grafana?

- Se puede crear paneles donde:
- Se muestren predicciones junto a los valores reales.
- Se generen alertas de anomalías.
- Se activen actuadores en base a recomendaciones inteligentes.

Aplicaciones de Inteligencia Artificial (IA) en Proyecto Hidropónico ISPC

Este documento presenta ejemplos de cómo se puede aplicar la Inteligencia Artificial (IA) en el sistema hidropónico automatizado desarrollado por estudiantes del ISPC. Las soluciones se centran en la predicción, detección de anomalías, optimización de recursos, visión por computadora y asistentes virtuales.

### 1. Predicción de Parámetros Críticos (IA Predictiva)

Objetivo: Anticipar valores de pH, temperatura, nivel de agua, flujo o concentración de nutrientes.
Cómo hacerlo:
- Usar modelos de regresión (como Random Forest, XGBoost o redes neuronales).
- Entrenar los modelos con datos históricos almacenados en MariaDB.
- Predecir cuándo ajustar nutrientes, encender bomba o controlar luz.
Tecnologías recomendadas: Python (scikit-learn, TensorFlow), Jupyter Notebook, MariaDB.

### 2. Detección de Anomalías

Objetivo: Identificar comportamientos inusuales como fallos de sensores, bomba dañada o crecimiento anormal.
Cómo hacerlo:
- Aplicar clustering no supervisado como K-Means o DBSCAN.
- Usar modelos de autoencoders para detectar desviaciones del comportamiento esperado.
Ejemplo: Si el flujo de agua baja mientras la bomba está activa, puede indicar una obstrucción.

### 3. Optimización de Recursos mediante IA (Recomendación)

Objetivo: Ajustar automáticamente iluminación, riego o nutrientes para maximizar el rendimiento.
Cómo hacerlo:
- Aplicar técnicas de optimización como algoritmos genéticos o aprendizaje por refuerzo (reinforcement learning).
- Usar condiciones pasadas y resultados para sugerir configuraciones óptimas. Ejemplo: Activar luces solo cuando la intensidad natural es baja y el crecimiento es insuficiente.

### 4. Análisis Visual de Cultivos

Objetivo: Detectar deficiencias nutricionales, plagas o crecimiento deficiente usando imágenes.
Cómo hacerlo:
- Integrar cámaras al sistema.

- Usar redes neuronales convolucionales (CNN) con TensorFlow o Keras.
- Detectar manchas, color de hojas o anomalías visuales.

### 5. Asistente Virtual o Sistema de Alertas Inteligente

Objetivo: Tener un sistema que no solo muestre datos, sino que interprete y sugiera acciones.
Cómo hacerlo:
- Programar reglas inteligentes con Node-RED y Python.
- Integrar bots de Telegram o WhatsApp para enviar alertas o sugerencias. Ejemplo: 'La temperatura del agua está fuera del rango óptimo para lechuga, activar enfriamiento'.

Resumen de Aplicaciones y Modelos IA
Función Inteligente | Datos Necesarios | Modelo IA Sugerido
Predicción de pH | pH, temperatura, TDS, flujo | Regresión (XGBoost)
Alertas automáticas | Todos los sensores | Detección de anomalías (Isolation Forest)
Recomendación de nutrientes | pH, tipo de cultivo, historial | Árboles de decisión
Control automático inteligente | Datos en tiempo real | Reinforcement learning
Clasificación visual de hojas | Imágenes de plantas | CNN con Keras

Mejoras Futuras con Inteligencia Artificial (IA) - Proyecto Hidropónico ISPC

Este documento presenta nuevas aplicaciones prácticas de Inteligencia Artificial (IA) que podrían integrarse como mejoras futuras en el sistema hidropónico IoT del Proyecto Integrador ISPC. Las ideas buscan potenciar la eficiencia, sostenibilidad y autonomía del cultivo, aprovechando datos históricos y sensores del sistema actual.

### 1. Análisis de Temporadas / Climas Locales para Adaptación del Cultivo

Descripción: Ajustar automáticamente el sistema según la época del año o clima exterior. la IA puede aprender patrones estacionales (ej. cambios en temperatura, humedad, pH) y adaptar la estrategia de cultivo.
Ejemplo práctico: En invierno se incrementa el uso de luces LED y se ajusta el caudal de riego; en verano se prioriza ventilación y mayor flujo de agua.
Modelo IA recomendado: Regresión estacional + K-Means clustering.

### 2. Reconocimiento de Crecimiento Anormal con Sensores de Peso o Volumen

Descripción: Detectar si una planta no crece al ritmo esperado, identificando posibles problemas en raíces o nutrientes insuficientes mediante sensores de masa o volumen.

Ejemplo práctico: Dos lechugas de la misma edad muestran diferencias de peso. IA detecta que una está por debajo del promedio y sugiere revisión manual.
Modelo IA recomendado: SVM o regresión lineal multivariable.

### 3. Sistemas de Riego Anticipado por Predicción de Sequía

Descripción: Predecir cuándo el nivel de humedad caerá por debajo de un umbral crítico y anticiparse al riego para evitar estrés hídrico en las plantas.

Ejemplo práctico: El modelo predice que la humedad descenderá a menos del 40% en 2 horas y activa preventivamente la bomba de riego.
Modelo IA recomendado: Modelos de series temporales (ARIMA, LSTM).

### 4. Clasificación de Cultivos Óptimos por Entorno

Descripción: Recomendar qué cultivo es más adecuado según condiciones actuales del entorno como temperatura, luz y humedad.
Ejemplo práctico: El sistema sugiere sembrar rúcula´´ en lugar de tomate debido a la baja intensidad lumínica de invierno.

Modelo IA recomendado: Clasificación supervisada (Árboles de decisión, Random Forest).

### 5. Planificación Automática de Cosecha y Siembra

Descripción: Calcular automáticamente los mejores momentos para sembrar y cosechar, maximizando el uso del espacio y el tiempo disponible en el sistema hidropónico.

Ejemplo práctico: La IA detecta que hay 10 días libres en el sistema y propone sembrar microverdes que se cosechan en 9 días.

Modelo IA recomendado: Optimización por restricciones (Constraint Solvers).

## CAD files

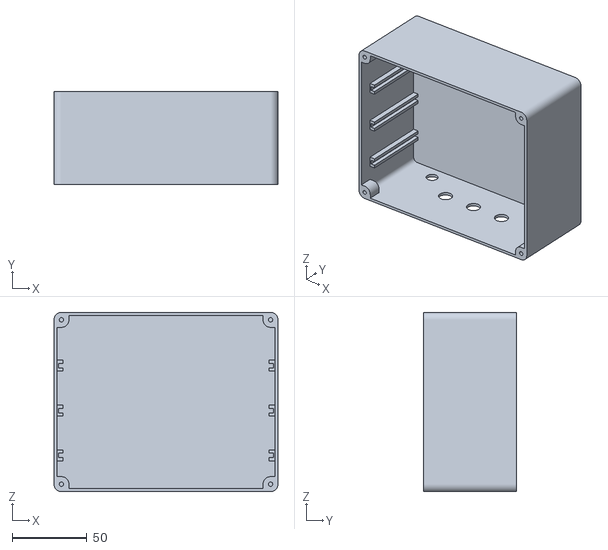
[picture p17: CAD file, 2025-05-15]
C-prototipos/modelos_3D_para_imprimir/Diseños_STL/caja_de_control_X1.stl
150.0 x 62.0 x 120.0

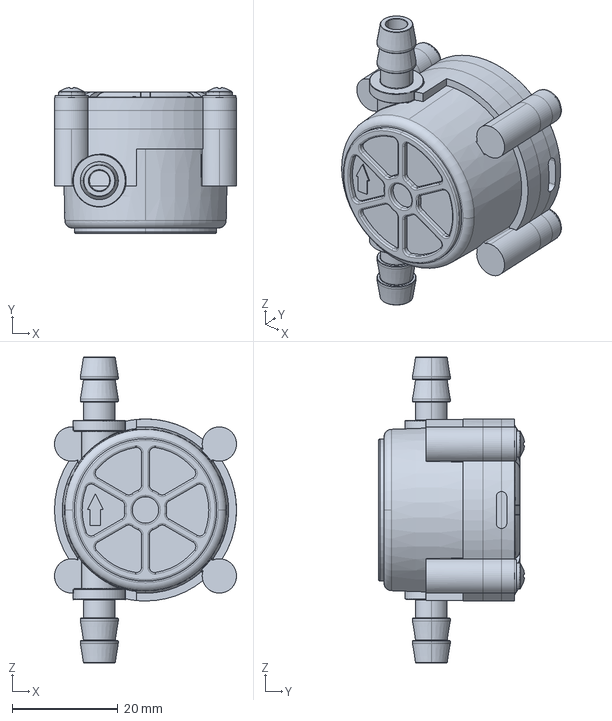
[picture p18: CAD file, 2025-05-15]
C-prototipos/modelos_3D_para_imprimir/Diseño_freecad/Sensor_caudalimetro.FCStd
34.5 x 27.6 x 58.0 mm

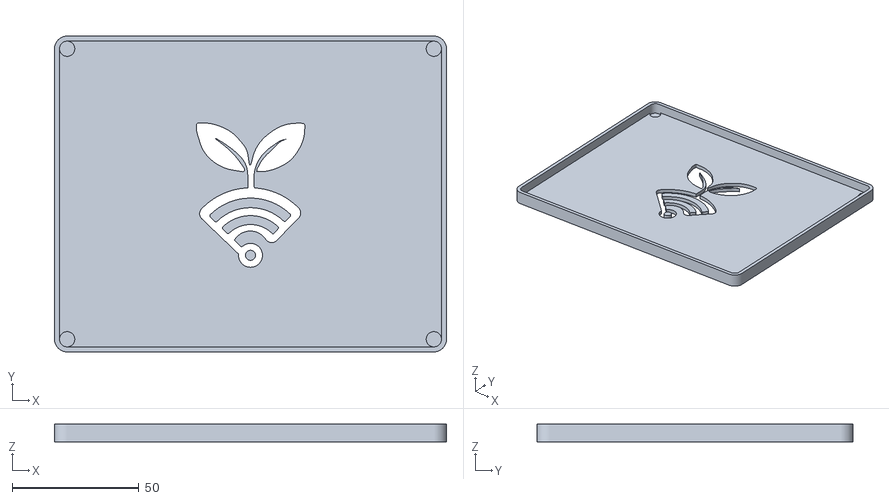
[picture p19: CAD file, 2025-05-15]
C-prototipos/modelos_3D_para_imprimir/Diseños_STL/tapas_gabinetes_X2.stl
154.5 x 124.5 x 7.00

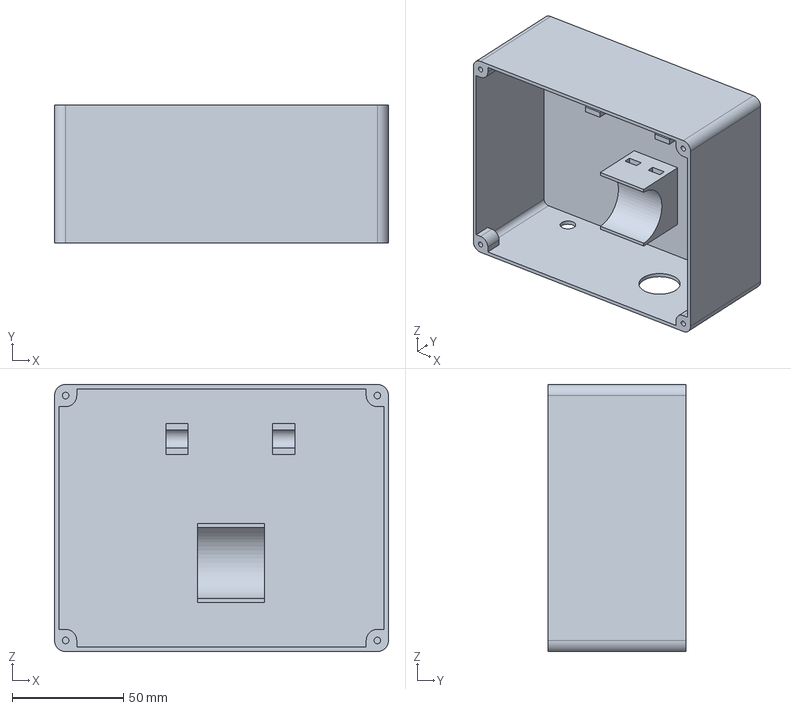
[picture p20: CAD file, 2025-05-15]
C-prototipos/modelos_3D_para_imprimir/Diseño_freecad/caja_de_maquinas.FCStd
150.0 x 62.0 x 120.0 mm

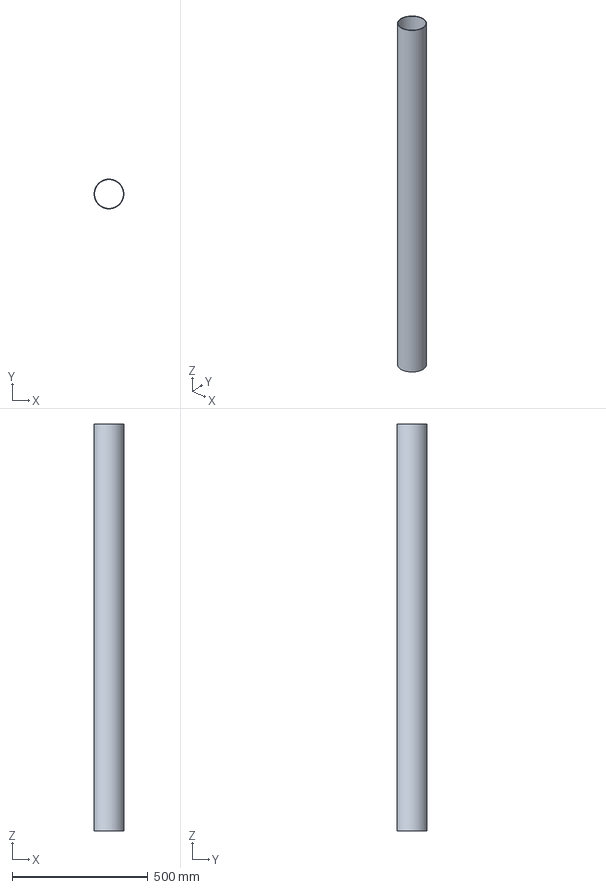
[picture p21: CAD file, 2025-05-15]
C-prototipos/modelos_3D_para_imprimir/Diseño_freecad/tubo_torre.FCStd
109.9 x 109.9 x 1500.0 mm

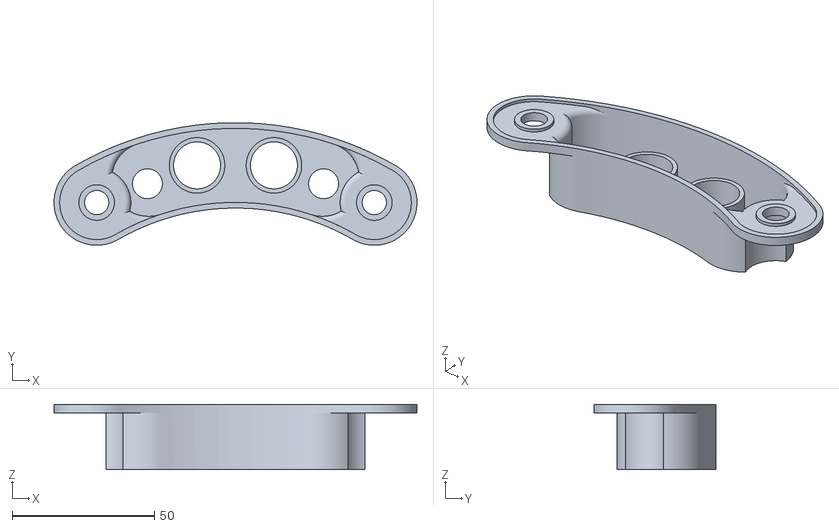
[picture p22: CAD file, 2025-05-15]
C-prototipos/modelos_3D_para_imprimir/Diseños_STL/soporte_sensores_agua_X1.stl
127.5 x 43.0 x 23.0

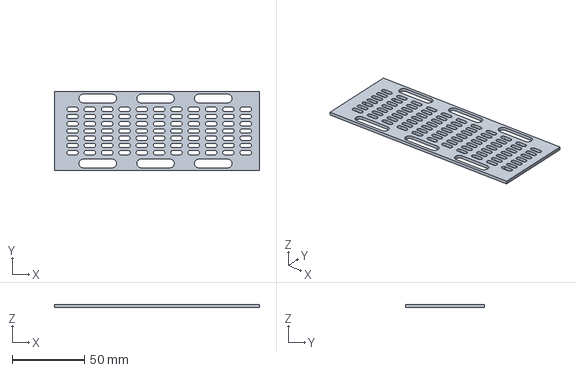
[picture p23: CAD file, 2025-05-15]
C-prototipos/modelos_3D_para_imprimir/Diseño_freecad/bandeja_electronica.FCStd
142.0 x 55.0 x 2.00 mm

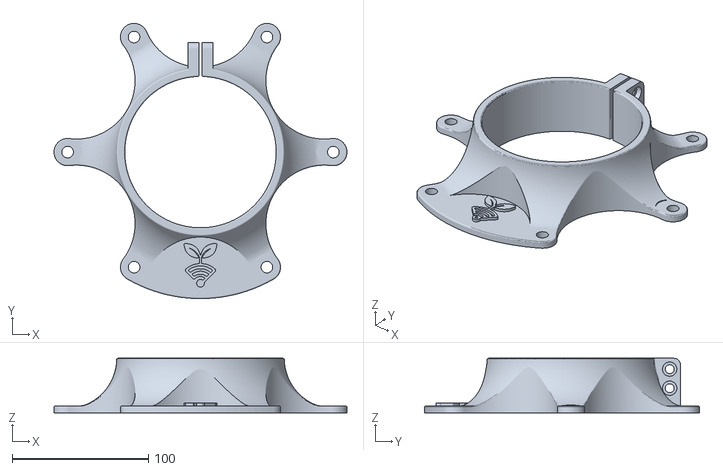
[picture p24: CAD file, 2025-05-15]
C-prototipos/modelos_3D_para_imprimir/Diseños_STL/brida_central_con_cierre_X1.stl
215.0 x 201.9 x 40.0

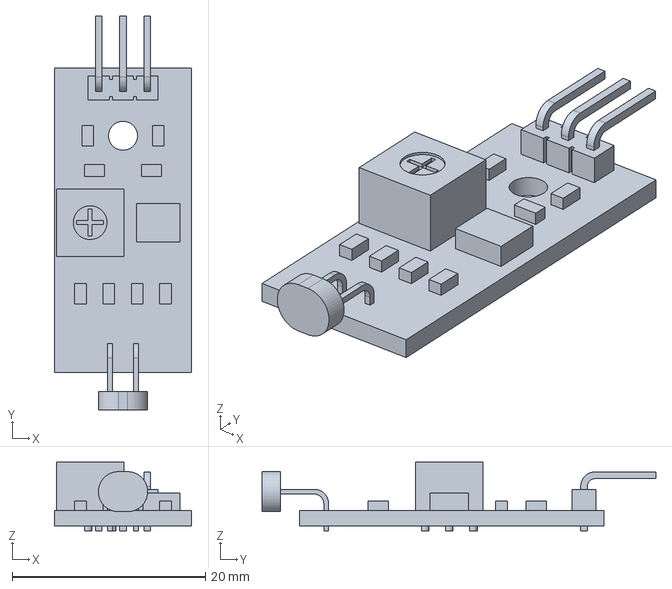
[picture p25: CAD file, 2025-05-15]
C-prototipos/modelos_3D_para_imprimir/Diseño_freecad/Sensor_LDR.FCStd
14.2 x 40.8 x 7.10 mm

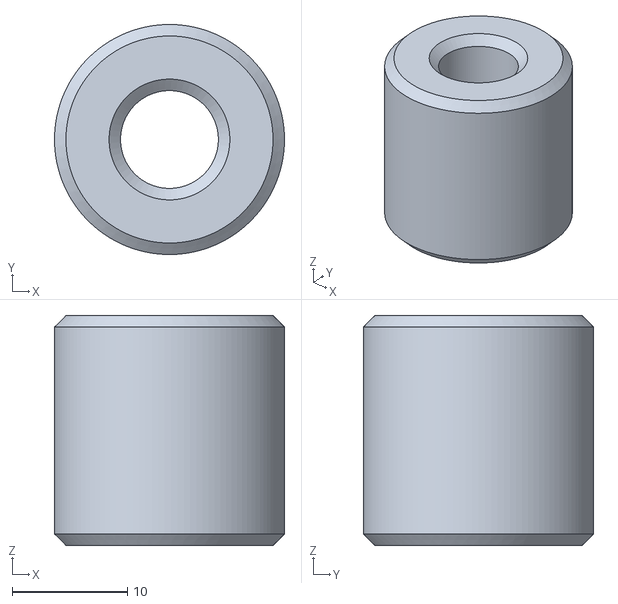
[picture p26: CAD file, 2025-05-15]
C-prototipos/modelos_3D_para_imprimir/Diseños_STL/separador_X4.stl
20.0 x 20.0 x 20.0

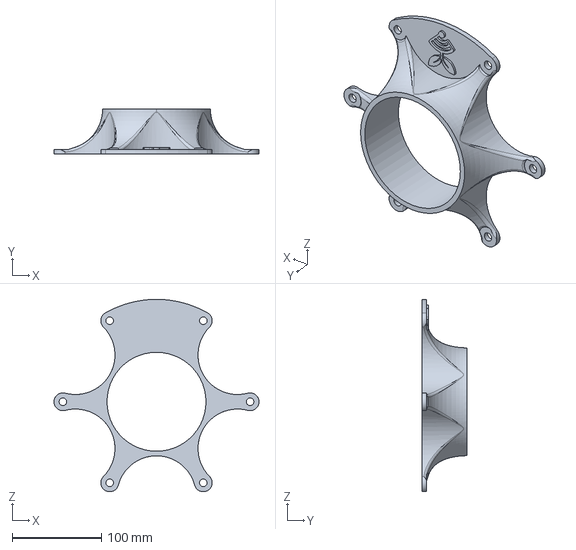
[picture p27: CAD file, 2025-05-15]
C-prototipos/modelos_3D_para_imprimir/Diseño_freecad/sOPORTE.FCStd
230.0 x 50.0 x 215.9 mm

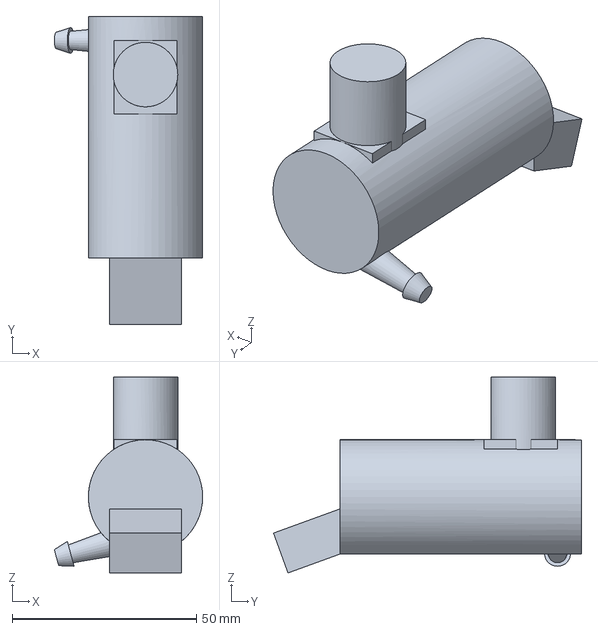
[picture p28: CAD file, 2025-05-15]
C-prototipos/modelos_3D_para_imprimir/Diseño_freecad/Bomba.FCStd
40.2 x 83.5 x 53.1 mm

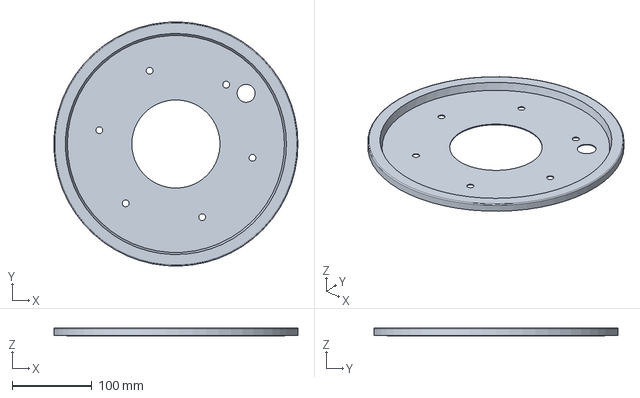
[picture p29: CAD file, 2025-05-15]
C-prototipos/modelos_3D_para_imprimir/Diseño_freecad/Tapa_tanque.FCStd
305.8 x 305.9 x 10.5 mm

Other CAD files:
C-prototipos/modelos_3D_para_imprimir/Diseño_freecad/Modelo_final.FCStd
C-prototipos/modelos_3D_para_imprimir/Diseños_STL/caja_de_maquinas_X1.stl
C-prototipos/modelos_3D_para_imprimir/Diseño_freecad/Caudalimetro.FCStd
C-prototipos/modelos_3D_para_imprimir/Diseños_STL/bandeja_electronica_X3.stl
C-prototipos/modelos_3D_para_imprimir/Diseño_freecad/tapas_gabinetes.FCStd
C-prototipos/modelos_3D_para_imprimir/Diseño_freecad/Sensor_DS18D20.FCStd
C-prototipos/modelos_3D_para_imprimir/Diseño_freecad/Sensor_DS3231_RTC.FCStd
C-prototipos/modelos_3D_para_imprimir/Diseño_freecad/Sensor_HC-SR04.FCStd
C-prototipos/modelos_3D_para_imprimir/Diseño_freecad/Sensor_MQ135.FCStd
C-prototipos/modelos_3D_para_imprimir/Diseño_freecad/brida.FCStd
C-prototipos/modelos_3D_para_imprimir/Diseño_freecad/brida_borde.FCStd
C-prototipos/modelos_3D_para_imprimir/Diseño_freecad/caja_de_control.FCStd
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

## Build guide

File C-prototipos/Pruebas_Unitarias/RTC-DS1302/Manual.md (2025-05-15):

### MANUAL 

## 📌 Descripción
    El manual muestra como utilizar un RTC DS1302. Logrando visualizar la fecha y hora en tiempo real de forma automatica

## 📂 Organización del Repositorio

 - 📦RTC DS1302
 - ┣ 📂.pio
 - ┃ ┗ 📂build
 - ┣ 📂include
 - ┃ ┗ 📜README
 - ┣ 📂lib
 - ┃ ┣ 📂Pantalla
 - ┃ ┃ ┣ 📜Pantalla.cpp
 - ┃ ┃ ┗ 📜Pantalla.h
 - ┃ ┗ 📜README
 - ┣ 📂src
 - ┃ ┗ 📜main.cpp
 - ┣ 📂test
 - ┃ ┗ 📜README
 - ┣ 📜.gitignore
 - ┣ 📜Manual.md
 - ┗ 📜platformio.ini

  ------------------------------

## Configuración  en `platformio.ini`:

```ini
[env:esp32dev]
platform = espressif32
board = esp32dev
framework = arduino
lib_deps = 
	adafruit/RTClib@^2.1.4
	adafruit/Adafruit BusIO@^1.17.0
	makuna/RTC@^2.5.0
    3304
monitor_speed = 115200
```

---------------------------------

## Conexiones Físicas

|**Pin DS1302**| **ESP32** |
|---|---|
| VCC | 3.3V |
| GND | GND |
| DAT | GPIO18 |
| CLK | GPIO5 |
| RST | GPIO19 |
---------------------

## Libreria Pantalla

### 📁 lib/pantalla/Pantalla.cpp

```cpp

#include "Pantalla.h"

void SR04::begin(uint8_t pinTrig, uint8_t pinEcho) {
  _pinTrig = pinTrig;
  _pinEcho = pinEcho;
  pinMode(_pinTrig, OUTPUT);
  pinMode(_pinEcho, INPUT);
  digitalWrite(_pinTrig, LOW);

  _state = IDLE;
  _lastTriggerMs = millis();
  _lastDistance = -1;
}

float SR04::read() {
  unsigned long nowMs = millis();
  unsigned long nowUs = micros();

  switch (_state) {
    case IDLE:
      if (nowMs - _lastTriggerMs >= INTERVAL_MS) {
        digitalWrite(_pinTrig, HIGH);
        _pulseStartUs = nowUs;
        _state = TRIGGER_PULSE;
      }
      break;

    case TRIGGER_PULSE:
      if (nowUs - _pulseStartUs >= 10UL) {
        digitalWrite(_pinTrig, LOW);
        _lastTriggerMs = nowMs;
        _state = WAIT_HIGH;
      }
      break;

    case WAIT_HIGH:
      if (digitalRead(_pinEcho) == HIGH) {
        _pulseStartUs = micros();
        _state = WAIT_LOW;
      } else if (nowMs - _lastTriggerMs >= TIMEOUT_HIGH_MS) {
        _lastDistance = -1;
        _state = IDLE;
      }
      break;

    case WAIT_LOW:
      if (digitalRead(_pinEcho) == LOW) {
        unsigned long durationUs = micros() - _pulseStartUs;
        _lastDistance = (durationUs * 0.0343f) / 2.0f;
        _state = IDLE;
      } else if (micros() - _pulseStartUs >= TIMEOUT_LOW_US) {
        _lastDistance = -1;
        _state = IDLE;
      }
      break;
  }

  return _lastDistance;
}
```

### 📁 lib/pantalla/Pantalla.h
```h

#ifndef PANTALLA_H
#define PANTALLA_H

#include <Arduino.h>
#include <RtcDS1302.h>

class Pantalla {
public:
    void mostrarHora(const RtcDateTime& dt);
    void mensajeInicio();
    void mensajeHoraInvalida();
    void mensajeComandoNoValido(const String& cmd);
};

#endif

```

## Código utilizado
### src/main.cpp

```cpp

include <ThreeWire.h>
#include <RtcDS1302.h>
#include "Pantalla.h"

// Conexiones de RTC DS1302
#define PIN_DAT 18 
#define PIN_CLK 5
#define PIN_RST 19

ThreeWire myWire(PIN_DAT, PIN_CLK, PIN_RST);
RtcDS1302<ThreeWire> Rtc(myWire);
Pantalla pantalla;

unsigned long tiempoAnterior = 0;
const unsigned long intervalo = 10000;  // 10 segundos

void setup() {
    Serial.begin(115200);
    while (!Serial);

    Rtc.Begin();

    if (Rtc.GetIsWriteProtected()) Rtc.SetIsWriteProtected(false);
    if (!Rtc.GetIsRunning()) Rtc.SetIsRunning(true);

    if (!Rtc.IsDateTimeValid()) {
        pantalla.mensajeHoraInvalida();
    }

    pantalla.mensajeInicio();
}

void loop() {
    if (millis() - tiempoAnterior >= intervalo) {
        tiempoAnterior = millis();
        RtcDateTime now = Rtc.GetDateTime();
        if (now.IsValid()) {
            Serial.print("[Auto] ");
            pantalla.mostrarHora(now);
        }
    }

    if (Serial.available()) {
        String comando = Serial.readStringUntil('\n');
        comando.trim();

        Serial.print("> ");
        Serial.println(comando);

        if (comando.equalsIgnoreCase("ver")) {
            RtcDateTime now = Rtc.GetDateTime();
            if (now.IsValid()) {
                pantalla.mostrarHora(now);
            } else {
                pantalla.mensajeHoraInvalida();
            }
        } else {
            pantalla.mensajeComandoNoValido(comando);
        }
    }
}
```

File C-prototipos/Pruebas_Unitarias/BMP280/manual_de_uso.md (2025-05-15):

# manual de uso Sensor BMP280  

## 📌 Descripción  

El BMP280 es un sensor barométrico fabricado por Bosch que permite medir:

Temperatura ambiente

Presión atmosférica

Altitud estimada (calculada a partir de la presión)

Este sensor se puede comunicar con el microcontrolador mediante los protocolos I2C o SPI. En este ejemplo se usa I2C, que es más sencillo de conectar.

## 🧰 Conexiones típicas (modo I2C)

BMP280 Pin	| Conexión al microcontrolador
VCC	| 3.3V
GND	| GND
SDA	Pin | SDA del micro (ej. GPIO21 en ESP32)
SCL	Pin | SCL del micro (ej. GPIO22 en ESP32)  

💡 La dirección I2C por defecto es 0x76, pero puede ser 0x77 en algunos módulos.

🧠 Métodos disponibles en la clase SensorBMP280

|Método| Descripción |
|---|---|
|SensorBMP280();| Costructor, no inicializa el sensor.|  
|bool begin();|Inicializa el sensor. Devuelve true si fue exitoso.|
|float getTemperature();| Devuelve la temperatura en °C.| 
|float readPressure();| Devuelve la presión en hPa (hectopascales).|
|float readAltitude(float seaLevelhPa);	| Devuelve la altitud estimada en metros, basándose en la presión atmosférica al nivel del mar.|
|bool isConnected();| Verifica si el sensor está conectado y funcionando.|  
    
## Uso basico de los metodos 

`bool begin()`  
Inicializa el sensor BMP280. Retorna true si se pudo comunicar correctamente, false si falló.

Ejemplo:

```cpp

if (!bmp.begin()) {
  Serial.println("❌ BMP280 no detectado.");
}  
```  

`float getTemperature()`  
Devuelve la temperatura actual en grados Celsius.

Ejemplo:

```cpp

Serial.println(bmp.getTemperature());  // 23.45  
```  

`float getPressure()`  
Devuelve la presión atmosférica en hectopascales (hPa).

Ejemplo:

```cpp

Serial.println(bmp.getPressure());  // 1013.25  
```  

`float getAltitude(float seaLevelhPa = 1013.25)`    
Calcula y devuelve la altitud estimada en metros, tomando la presión al nivel del mar como parámetro.

Ejemplo:

```cpp

Serial.println(bmp.getAltitude());  // 142.50 (metros)
```

## 📦 Ejemplo de uso básico
```cpp

#include <Arduino.h>
#include "SensorBMP280.h"

SensorBMP280 bmp;
unsigned long Millis_anterior = 0;
const unsigned long intervalo = 5000; // 5 segundos

void setup() {
  Serial.begin(9600);
  if (bmp.begin()) {
    Serial.println("BMP280 conectado correctamente.");
  } else {
    Serial.println("Error al conectar el BMP280. Se intentará de nuevo periódicamente.");
  }
}

void loop() {
  unsigned long Millis_actual = millis();

  // Reintenta conexión si no está conectado
  if (!bmp.isConnected()) {
    static unsigned long ultimo_intento = 0;
    if (Millis_actual - ultimo_intento >= 10000) { // Reintenta cada 10 segundos
      ultimo_intento = Millis_actual;
      if (bmp.begin()) {
        Serial.println("Reconexión exitosa con el BMP280.");
      } else {
        Serial.println("Reintento fallido: BMP280 no conectado.");
      }
    }
    return; // No intentamos leer datos si no está conectado
  }

  if (Millis_actual - Millis_anterior >= intervalo) {
    Millis_anterior = Millis_actual;

    float temp = bmp.readTemperature();
    float presion = bmp.readPressure();
    float altitud = bmp.readAltitude();

    if (isnan(temp) || isnan(presion) || isnan(altitud)) {
      Serial.println("Error al leer datos del BMP280.");
      return;
    }

    Serial.println("-------------");
    Serial.print("Temperatura: ");
    Serial.print(temp);
    Serial.println(" °C");

    Serial.print("Presión: ");
    Serial.print(presion);
    Serial.println(" hPa");

    Serial.print("Altitud estimada: ");
    Serial.print(altitud);
    Serial.println(" m");
  }
}

```  

## 🧱 Estructura del código
Se creó una clase llamada SensorBMP280 que permite:

### 🏗️ Inicializar el sensor
```cpp
SensorBME280 bmp;
bmp.begin();  
```
### 🌡️ Obtener lecturas
```cpp

float temp = sensor.getTemperature();      // °C
float hum = sensor.getHumidity();          // %
float pres = sensor.getPressure();         // hPa
float alt = sensor.getAltitude();          // m (estimado)  
```  

🧠 La altitud se calcula usando una presión de referencia a nivel del mar. Por defecto se usa 1013,25 hPa, pero se puede cambiar:

```cpp
sensor.setSeaLevelPressure(1015.0);  
```  

## 📘 Consideraciones a tener en cuenta
- Si se aprecian lecturas erráticas, revisar bien las conexiones.

- Este sensor no mide humedad, a diferencia de su hermano el BME280.

- Si el sensor no responde, probar con la dirección 0x77 en el método bmp.begin(0x77). 

- Evitar colocar el sensor cerca de fuentes de calor o humedad directas (ej: motores, manos respiración).

- Si el valor de altitud es inestable, revisar el valor de presión de referencia (se puede obtener de una estación meteorológica local).

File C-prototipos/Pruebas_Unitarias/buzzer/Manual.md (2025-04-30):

### MANUAL

## 📌 Descripción

Este manual demuestra cómo utilizar un **buzzer pasivo** con una librería personalizada en **ESP32**, implementando un modelo no bloqueante basado en `millis()` y tres niveles de alarma definidos por frecuencia y tiempos de encendido/apagado.

------------------------

## 📂 Organización del Repositorio

- 📦buzzer
-  ┣ 📂.pio
-  ┃ ┗ 📂build
-  ┣ 📂include
-  ┃ ┗ 📜README
-  ┣ 📂lib
-  ┃ ┗ 📜README
-  ┣ 📂src
-  ┃ ┗ 📜main.cpp
-  ┣ 📂test
-  ┃ ┗ 📜README
-  ┣ 📜.gitignore
-  ┣ 📜buzzer.cpp
-  ┣ 📜buzzer.h
-  ┣ 📜Manual.md
-  ┗ 📜platformio.ini

------------------------

## 🔧 Configuración crítica en `platformio.ini`

```ini
[env:esp32dev]
platform    = espressif32
board       = esp32dev
framework   = arduino
monitor_speed = 115200
build_flags  = -I${PROJECT_DIR}/lib/Buzzer
```

## LIbreria Personalizada

```cpp
#ifndef BUZZER_H
#define BUZZER_H

#include <Arduino.h>

/// Niveles de alarma
enum AlarmLevel : uint8_t {
  A_NONE = 0,
  A_LOW,
  A_MEDIUM,
  A_HIGH
};

class Buzzer {
public:
  Buzzer(uint8_t pin);
  void begin();                    // Configura el pin y estado inicial
  void setLevel(AlarmLevel lvl);   // Cambia el patrón de alarma
  void update();                   // Debe llamarse en loop(): no bloqueante

private:
  struct AlarmParams { uint16_t freq; uint16_t onDur; uint16_t offDur; };
  static const AlarmParams params[4];

  uint8_t       _pin;
  AlarmLevel    _current;
  bool          _isOn;
  unsigned long _lastTs;
};

#endif
```

```cpp
#include "buzzer.h"

// {frecuencia (Hz), tiempo ON (ms), tiempo OFF (ms)}
const Buzzer::AlarmParams Buzzer::params[4] = {
  {   0,   0,   0 },  // A_NONE
  {1000, 100, 900},  // A_LOW    100 ms ON / 900 ms OFF
  {1500, 200, 800},  // A_MEDIUM 200 ms ON / 800 ms OFF
  {2000, 300, 700}   // A_HIGH   300 ms ON / 700 ms OFF
};

Buzzer::Buzzer(uint8_t pin)
  : _pin(pin), _current(A_NONE), _isOn(false), _lastTs(0) {}

void Buzzer::begin() {
  pinMode(_pin, OUTPUT);
  noTone(_pin);
  _lastTs = millis();
}

void Buzzer::setLevel(AlarmLevel lvl) {
  _current = lvl;
  _isOn    = false;
  _lastTs  = millis();
}

void Buzzer::update() {
  if (_current == A_NONE) {
    noTone(_pin);
    return;
  }
  unsigned long now = millis();
  const auto &p = params[_current];

  if (_isOn) {
    if (now - _lastTs >= p.onDur) {
      noTone(_pin);
      _isOn   = false;
      _lastTs = now;
    }
  } else {
    if (now - _lastTs >= p.offDur) {
      tone(_pin, p.freq);
      _isOn   = true;
      _lastTs = now;
    }
  }
}
```

------------------------
## Conexiones Físicas

| **Buzzer** | **ESP32** |
| --- | --- |
| Señal (positivo) | GPIO 15 |
| GND (negativo) | GND |

------------------------

## Código de Ejemplo (src/main.cpp)

```cpp
#include <Arduino.h>
#include "buzzer.h"

static const uint8_t BUZZER_PIN     = 15;
static const unsigned long INTERVAL = 5000; // Cambiar nivel cada 5 s

Buzzer buzzer(BUZZER_PIN);
AlarmLevel levels[] = { A_LOW, A_MEDIUM, A_HIGH, A_NONE };
size_t      idx       = 0;
unsigned long lastChange = 0;

void setup() {
  Serial.begin(115200);
  while (!Serial);

  buzzer.begin();
  buzzer.setLevel(levels[idx]);
  Serial.println("=== Prueba Buzzer iniciada ===");
}

void loop() {
  // 1) Ejecuta la lógica no bloqueante del buzzer
  buzzer.update();

  // 2) Cada INTERVAL cambia nivel y lo reporta
  unsigned long now = millis();
  if (now - lastChange >= INTERVAL) {
    idx = (idx + 1) % (sizeof(levels)/sizeof(levels[0]));
    buzzer.setLevel(levels[idx]);
    Serial.print("Nivel de alarma: ");
    Serial.println(idx); // 0=Low,1=Med,2=High,3=None
    lastChange = now;
  }
}
```

------------------------

## Solucion de Problemas

| **Síntoma** | **Causa Probable** | **Solución** |
|---|---|---|
| No suena el buzzer | Pin mal configurado o incorrecto | Verificar `BUZZER_PIN` y `pinMode()` en `begin()` |
| Patrón de sonido constante | `_isOn` nunca cambia porque `update()` no se llama | Asegurarse de llamar a `buzzer.update()` en cada `loop()` |
| Alertas no varían | `setLevel()` no invocado o nivel inválido | Revisar la lógica de cambio de niveles en `loop()` |
| Ruido o clics no deseados | Frecuencias altas o duraciones muy cortas | Ajustar valores en `params[]` según el buzzer utilizado |

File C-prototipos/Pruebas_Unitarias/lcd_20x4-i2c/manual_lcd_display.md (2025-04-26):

# Manual de uso de la librería lcd_display para ESP32 y LCD 20x4 I2C

Este manual describe cómo utilizar la librería `lcd_display` para controlar una pantalla LCD 20x4 que se comunica a través del protocolo I2C con una placa ESP32.

## Archivos Incluidos

* `lcd_display.h`: Archivo de encabezado que declara las funciones para interactuar con el LCD.
* `lcd_display.cpp`: Archivo de implementación que contiene el código fuente de las funciones.

## Instalación

1.  Guarda los archivos `lcd_display.h` y `lcd_display.cpp` en la misma carpeta de tu proyecto de Arduino (o PlatformIO) junto con tu archivo principal (`.ino` o `.cpp`).

## Uso en tu Código Principal (`main.cpp` o `.ino`)

### 1. Incluir la Librería

En la parte superior de tu archivo principal, incluye el archivo de encabezado de las librerias:

```cpp
#include <Wire.h>
#include <LiquidCrystal_I2C.h>
#include "lcd_display.h"

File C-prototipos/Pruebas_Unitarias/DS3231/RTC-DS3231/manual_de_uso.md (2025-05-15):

# Módulo RTC DS3231 - Manual de Uso

Este módulo está diseñado para facilitar el uso del reloj de tiempo real DS3231 en controladores como el ESP32, y además permite actualizar automáticamente la hora usando servidores NTP a través de internet.

---

## 📦 Archivos del módulo

```swift
/DS3231/
    DS3231.h
    DS3231.cpp    
/WiFiManagerESP32/
    WiFiManagerESP32.h
    WiFiManagerESP32.cpp
/WiFiCred/
    WiFiCred.h
/src/
    main.cpp
/manual_de_uso.md   

```  

## 🔌 Conexión del módulo DS3231

| DS3231 | ESP32 |
|---|---|
| VCC | 3.3V o 5V |
| GND | GND |
| SDA | GPIO21 (por defecto I2C) |
| SCL | GPIO22 (por defecto I2C) | 
   
⚠️ El ESP32 tolera 5V en I2C, pero si querés estar más seguro, usá una versión de DS3231 con regulador a 3.3V.

---

## 📚 Librerías necesarias

Debemos instalar las siguientes librerías:

- `RTClib` (de Adafruit)
- `WiFi` (incluida con ESP32)
- `time` (incluida con ESP32)

---

## 🔧 Inicialización

```cpp
#include "DS3231.h"

DS3231Clock reloj

void setup() {
  Serial.begin(115200);
  reloj.begin();
}  
```  

## 🕐 Obtener la hora actual
```cpp
DateTime actual = reloj.getHora();
Serial.println(actual.timestamp());  
```  

## 🌍 Sincronizar con la hora mundial (NTP)
Este método permite que tu módulo DS3231 se sincronice con la hora oficial de internet. Para ello, es necesario conectarse primero a una red WiFi.

📁 Archivos necesarios:
```swift
/WiFiManager
    WiFiManager.h
    WiFiManager.cpp
/WiFicred
    WiFiCred.h  
```  

## 👣 Pasos:
1. Conectar el ESP32 a la Red WiFi
Primero, debes utilizar la clase WiFiManager para establecer conexión WiFi.

```cpp
#include "WiFiManager.h"

WiFiManager wifi;

void setup() {
  Serial.begin(9600);

  wifi.begin();
}

```    
  
La clase WiFiManager leerá el SSID y la password desde WiFiCred.h, donde estan definidas las credenciales de la siguiente manera:

```cpp
#define WIFI_SSID "TuSSID"
#define WIFI_PASSWORD "TuContraseña"    
```   
Este archivo no sera subido al repositorio con la ayuda de .gitignore.    
  
2. Sincronizar el RTC con la Hora Mundial (NTP)  

Una vez conectado a WiFi, se puede sincronizar la hora utilizando el método sincronizarConNTP() de la clase DS3231Clock.

### Código básico para sincronizar la hora:

```cpp
#include <Arduino.h>
#include "DS3231.h"
#include "WiFiManager.h"

WiFiManager wifi;
DS3231Clock reloj;

unsigned long Ultima_muestra = 0;
const unsigned long Intervalo_muestra = 2000;

void setup() {
  Serial.begin(9600);

  wifi.conectar();
  reloj.begin();

  if (wifi.estaConectado()) {
    reloj.sincronizarConNTP();
  } else {
    Serial.println("No hay conexión WiFi, no se sincronizará con NTP.");
  }
}

void loop() {
  unsigned long Millis_actual = millis();

  if (Millis_actual - Ultima_muestra >= Intervalo_muestra) {
    Ultima_muestra = Millis_actual;

    String hora = reloj.getTimeString();
    Serial.println(hora);
  }
}

```  

Este proceso:

- Se conecta automáticamente al servidor pool.ntp.org.

- Ajusta la hora tomando en cuenta el huso horario de Argentina (UTC-3).

- Actualiza el módulo RTC DS3231 con la hora obtenida de internet.

- Imprime en el monitor serie la nueva hora configurada.  

Con estos pasos el RTC obtiene la hora mundial, y puede usarse incluso sin conexión después.

## ⚙️ Métodos disponibles
`DS3231Clock()`  
Constructor. Crea un objeto RTC sin iniciarlo aún.

`void begin()`  
Inicializa el módulo DS3231. Debe llamarse en setup(). También verifica si el RTC perdió alimentación.

`void setDateTime(int year, int month, int day, int hour, int minute, int second)`  
Establece la fecha y hora manualmente.

Ejemplo:

```cpp
  
reloj.setDateTime(2025, 5, 15, 12, 30, 0);  // 15 de mayo 2025, 12:30:00  
```  

`String getTimeString()`  
Devuelve la hora y fecha actual en formato "YYYY-MM-DD HH:MM:SS" como String.

Ejemplo:

```cpp

Serial.println(reloj.getTimeString());  // "2025-05-15 12:30:00"  
```  

`uint32_t getEpochTime()`  
Devuelve el tiempo actual en formato Unix timestamp (segundos desde 1970).

Ejemplo:

```cpp

uint32_t t = reloj.getEpochTime();  // 1700000000, por ejemplo  
```  

`void sincronizarConNTP()`  
Actualiza la hora del RTC usando un servidor NTP, si el ESP32 está conectado a WiFi.

Requisitos:

Llamar solo si `WiFi.status() == WL_CONNECTED.`

Utiliza `"pool.ntp.org"` como servidor NTP por defecto.

## 💡 Consideraciones a tener en cuenta
- Se puede sincronizar con NTP solo una vez al arrancar, o programar una actualización periódica.  

- El ESP32 debe tener acceso a internet en el momento de sincronizar.  
  
- Una vez configurada, el DS3231 mantiene la hora internamente incluso si se corta la energía (gracias a su batería interna).

- Se puede sincronizar periódicamente llamando a sincronizarConNTP() cada cierto tiempo, por ejemplo, una vez por semana.

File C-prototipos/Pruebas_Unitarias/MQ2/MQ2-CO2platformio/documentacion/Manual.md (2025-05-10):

# SENSOR: MQ-2 (o MQ-135)

La siguiente prueba unitaria esta destinada a la familia de sensores MQ-N para la medicion de CO2, mediante la utilizacion de la libreria MQUnifiedsensor@^3.0.0 para facilitacion de la calibracion y las cuentas de evaluacion de PPM del gas indicado

**a considerar**
El sensor MQ-2 no esta destinado a la medicion de CO2. La mayoria de los sensores de la familia MQ tienen como fin la deteccion de gases inflamables y humo. Una excepcion es, por ejemplo el sensor MQ-135 que posee una gama de medicion de gases mas amplia.

### Caracteristicas de sensores MQ-N
Son sensores analogicos semiconductores resistivos, que mediante la interaccion con determinados elementos del ambiente varian su resistencia. Es mediante la comparacion de la variacion de resistencia en presencia de aire limpio, y el aire con presencia del gas a medir que podemos calcular la concentracion de dicho gas en el ambiente

Esto requiere que el sensor en cuestion se calibre. Segun la documentacion se recomienda entre 10 y 24hs la primera vez que se encienda (sea nuevo, o por que tiene varios meses de NO uso). En uso regular el mismo levanta temperatura en unos 5/10 minutos.

La calibracion ante la presencia de gases se logra mediante la documentacion de cada modelo del sensor en el que se indican curvas de sensibilidad con la carga resistiva del modelo en cuestion.

### Libreria: MQUnifiedsensor@^3.0.0

- Documentacion de la libreria: [link-a-la-libreria](https://github.com/miguel5612/MQSensorsLib)
- En el "REAMDE.md" de la libreria se encuentran los links a las datasheets de los diferentes sensores que permite gestion la libreria. Se agregan los dos posibles a utilizar para evitar futuras descargas.

El usuario creador de la misma deja bien documentado ejemplo de uso de las funciones planteadas en el link previo.
La libreria tiene la intencion de facilitar la configuracion y calibracion de varios modelos de la flia MQ-N en proyectos que utilizan microcontroladores como Arduino, o ESP.

**A considerar** Los sensores MQ requieren un voltage de 5V. Casos como en el ESP8266 se requieren dos fuentes. Pero para con el ESP32 se indica lo siguiente
ESP32 WROOM 32D
-- The ESP32 WROOM 32D does not need an external power supply. A0 goes to PIN36, Vcc to 3v3 and GND to any GND port on the board. Check the ESP2/ESP32_WROOM_32 folder to fixing the measuring issue when connecting to wifi.--

### Codigo

** SensorCO2.h** 
```cpp
//=============================================
// Librerias y condicional
//=============================================
#ifndef SENSORCO2_H
#define SENSORCO2_H
#include <Arduino.h>
#include "MQUnifiedsensor.h"  // Librería para sensors MQ, nos simplifica la lectura y calibracion
//=============================================
// Configuración del sensor MQ2 para medir CO2
//=============================================
// Este formato estandar viene defindo en la documentacion de la  libreria MQUnifiedsensor
// Son los parametros que luego llamamos en la funcion [SensorCO2::SensorCO2(int pin)]
// RS refiere a la resistencia del sensor y RO a la resistencia en aire limpio. Esta ultima es la que se usa de referencia
#define BOARD               F("ESP32")  // Identificador de la placa
#define VCC                 3.3f        // Voltaje de alimentación (V)
#define RL_KOHM             10.0f       // Resistencia de carga en kilo-ohmios (kΩ)
#define ADC_RES             12          // Resolución ADC del ESP32 (12 bits = 4095)
#define RATIO_CLEAN_AIR     9.8f        // Rs/Ro en aire limpio según datasheet
#define CALIB_DELAY_MS      2000          // Tiempo de espera para estabilizar el sensor (ms)
// Por suerte la configuracion para el MQ135 es simple, comentar y descomentar lo siguiente
//#define RATIO_CLEAN_AIR     3.8f 
//#define RL_KOHM             20.0f
class SensorCO2 {
public:
    explicit SensorCO2(int pin);        // PIN a definir segun la planilla de sensores
    void begin();                       // Inicializa el sensor y la librería MQUnifiedsensor
    int readRaw();                      // Lectura cruda del sensor (ADC)  
    float readResistance();             // Lectura de resistencia del sensor (Rs) en KOhms
    float readRatio();                  // Lectura de la relación Rs/Ro
    float readPPM();                    // Lectura de PPM de CO2
private:
    int sensorPin;
    float Ro;                           // Resistencia en aire limpio (kΩ)
    MQUnifiedsensor mq;                // Objeto de la librería MQUnifiedsensor para el sensor MQ sea el 2, o el 135
};
#endif 
```

**SensorCO2.cpp** 
```cpp
#include "SensorCO2.h"
SensorCO2::SensorCO2(int pin)                                   // Inicializa el sensor mq, usando la funcion mq de la libreria MQUnifiedsensor
  : sensorPin(pin)
  , mq(BOARD, VCC, ADC_RES, sensorPin, F("MQ-2")){}             // placa, voltaje, resolución ADC, pin, tipo de sensor    
//, mq(BOARD, VCC, ADC_RES, sensorPin, F("MQ-135")) {} 
        
//=============================================
// Funciones de la clase para llamar en el SETUP
//=============================================
void SensorCO2::begin() {
    Serial.println("Inicializando mq y calibrando Ro...");
    mq.setRegressionMethod(1);                                 // regresión exponencial (curva log-log)
    mq.setRL(RL_KOHM);                                 
    mq.init();                                                 // inicializa ADC interno del sensor
    mq.update();                                               // Actualiza medición interna
    delay(CALIB_DELAY_MS);                                                 
    Ro = mq.calibrate(RATIO_CLEAN_AIR);                    // Calibración usando el valor de Rs/Ro en aire limpio
    Serial.print("Calibración completa. Ro = ");
    Serial.print(Ro, 2);
    Serial.println(" kΩ\n");
}
//=============================================
// Funciones de la clase para llamar en el LOOP
//=============================================
int SensorCO2::readRaw() {
    return analogRead(sensorPin);               // Lectura del valor analogico
}
float SensorCO2::readResistance() {
    mq.update();                               // Actualiza medición interna
    float voltage = mq.getVoltage();           // Obtiene voltaje del sensor                  
    float rs = (VCC - voltage) / voltage * mq.getRL();  // Calcula Rs(res del sensor)
    return rs;
}
float SensorCO2::readRatio() {                  // Calcula la relación Rs/Ro (res sensor/ res aire limpio)
    return readResistance() / Ro;
}
float SensorCO2::readPPM() {
    mq.update();                               // refrescar medición
    return mq.readSensor();                    // devuelve PPM para mq
}
```

**main.cpp**
```cpp
//=============================================
// Librerias y condicional
//=============================================
#include <Arduino.h>
#include "SensorCO2.h"

#ifndef SENSORGAS_PIN
#define SENSORGAS_PIN 15 
#endif
//=============================================
// INCIALIZACION/DEFINICIONES
//=============================================
SensorCO2 co2Sensor(SENSORGAS_PIN);
//=============================================
// INICIALIZACION del MONITOR SERIAL + SENSOR
//=============================================
void setup() {
    Serial.begin(115200);
    delay(100);
    Serial.println("=== Iniciando lectura de CO2 con MQ ===");
    co2Sensor.begin();
}
//=============================================
// CICLO DE LECTURA DEL SENSOR
//=============================================
// 1- co2Sensor.readRaw(); lectura analogica sin mas
// 2- co2Sensor.readResistance(); lee la resistencia del sensor en ese determinado instante
// 3- co2Sensor.readRatio(); hace la relacion entre la res anterior, y la resistencia de referencia
// 4- co2Sensor.readPPM(); hace la lectura y devuelve la PPM del gas en cuestion
//=============================================
void loop() {
    int raw    = co2Sensor.readRaw();
    float rs   = co2Sensor.readResistance();
    float ratio= co2Sensor.readRatio();
    float ppm  = co2Sensor.readPPM();

    Serial.print("Lectura analogica: ");     Serial.print(raw);
    Serial.print("  Resistencia Sensor: ");  Serial.print(rs, 2);    Serial.print(" kΩ");
    Serial.print("  Relacion Rs/Ro: ");      Serial.print(ratio, 3);
    Serial.print("  CO2 PPM: ");             Serial.println(ppm, 1);

    delay(1000);
}
```

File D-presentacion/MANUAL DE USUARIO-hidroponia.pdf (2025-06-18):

Manual de Usuario

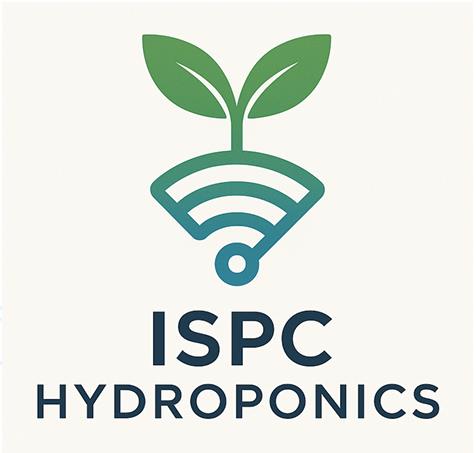
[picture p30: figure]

Índice

1- Introducción
2- Componentes del Sistema 3- Requisitos Previos
4- Encendido y Funcionamiento 5- Visualización de Datos
6- Control Remoto
7- Solución de Problemas
8- Recomendaciones
9- Contacto y Soporte

### 1. Introducción

Este sistema hidropónico automatizado está diseñado para facilitar el cultivo sin suelo mediante sensores, microcontroladores y una interfaz visual. El sistema permite monitorear y controlar variables como temperatura, TDS (sólidos disueltos), caudal de agua y nivel del tanque, todo desde una red local o de forma remota.

### 2. Componentes del Sistema

-Microcontrolador: ESP32
-Sensores:
- Temperatura (DS18B20)
- Sensor de TDS (conductividad)
- Sensor de caudal
- Sensor ultrasónico de nivel -Actuadores:
- Relé conectado a bomba de agua -Software:
- Arduino IDE (para cargar el código al ESP32)
- Mosquitto MQTT (broker de mensajería)
- Node-RED (automatización y almacenamiento)
- MariaDB (base de datos)
- Grafana (visualización en dashboards)

### 3. Requisitos Previos

Hardware:

- Fuente de alimentación adecuada para la bomba y el ESP32.
- Conexión a red WiFi estable.
- Cables, jumpers, resistencias.
Software:
- Arduino IDE instalado
- Broker MQTT funcionando (local o en red)
- Node-RED configurado

- Base de datos MariaDB /MySQL activa
- Grafana operativa

### 4. Encendido y Funcionamiento

Paso 1: Cargar el código
- Abre el archivo .ino desde la carpeta /Codigo_ESP32/.
- Configura el nombre y contraseña del WiFi y la IP del broker MQTT en el código.
- Carga el programa al ESP32 mediante Arduino IDE.
Paso 2: Conectar sensores y bomba
- Asegúrate de conectar cada sensor en su pin correspondiente como indica el esquema del repositorio.
- La bomba debe ir conectada al relé y este a un pin digital del ESP32.
Paso 3: Energizar el sistema
- Conecta el sistema a la fuente de alimentación.
- El ESP32 se conectará al WiFi y comenzará a enviar datos al broker MQTT.

### 5. Visualización de Datos

Node-RED
- Accede al panel de Node-RED (generalmente desde http://localhost:1880 o la IP del servidor).
- El flujo recibirá datos desde MQTT y los guardará en la base de datos.
Grafana
- Abre Grafana desde el navegador.
- Inicia sesión y accede al dashboard del proyecto.
- Visualiza los datos en tiempo real: temperatura, TDS, caudal, nivel del tanque, etc.

### 6. Control Remoto

Desde Node-RED se puede:
- Encender/apagar la bomba manualmente.
- Configurar automatizaciones (por ejemplo, que la bomba se active si TDS < 300).
- Enviar comandos desde el panel o integrarlos con Telegram para activar funciones a distancia.

- El ESP32 interpreta estos comandos desde un topic MQTT de control, por ejemplo: /hidroponico/control/bomba.

### 7. Solución de Problemas

Problema | Posible causa | Solución
No hay datos en Grafana | Fallo en MQTT o Node-RED | Verificar conexión MQTT y flujo de Node-RED
ESP32 no conecta al WiFi | Error en credenciales | Revisar configuración en el código
Sensor devuelve 0 o NaN | Mala conexión o fallo del sensor | Verificar cableado o reemplazar sensor
Bomba no responde | Relé defectuoso o pin incorrecto | Verificar conexión y código del pin de control

### 8. Recomendaciones

- Recalibrar los sensores de TDS periódicamente.
- Utilizar nombres únicos para cada topic MQTT si se usan múltiples cultivos.
- Hacer backups regulares de la base de datos.
- Usar fuentes confiables para alimentar la bomba y el ESP32.
- Proteger el sistema físico del agua y la humedad.

### 9. Contacto y Soporte

Para soporte técnico, contactarse con el equipo de desarrollo del ISPC o visitar el repositorio oficial:

https://github.com/ISPC-PI-II-2024/Proyecto_hidroponico

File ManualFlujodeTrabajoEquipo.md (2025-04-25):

https://github.com/ISPC-PI-II-2024/Proyecto_hidroponico.git
# 🛠️ Manual de trabajo en equipo con Git

## 📌 Objetivo
Organizar el desarrollo colaborativo de hardware y software usando un flujo de trabajo por ramas en Git. Cada integrante trabaja de forma aislada en su rama y se integran los cambios de forma progresiva.

---

## 🌳 Estructura de ramas

| Rama | Propósito |
|---|---|
| `main` | Versión **estable y lista** para producción o entrega final. |
| `development` | Versión de desarrollo que reúne cambios funcionales para testeo. |
| `feature-*` | Ramas individuales de cada integrante o para tareas específicas. |

Ejemplos:
- `feature-julian-sensorXXX`
- `feature-lucas-webapp`
- `feature-alina-componenteXXX`

---

## 🚀 Flujo de trabajo

### 1. Clonar el repositorio y crear tu rama de trabajo

```bash
git clone https://github.com/usuario/repositorio.git
cd repositorio
git checkout development
git pull origin development
git checkout -b feature-tu-nombre
```

---

### 2. Trabajar normalmente en tu rama

```bash
git add .
git commit -m "Mensaje claro del cambio realizado"
git push origin feature-tu-nombre
```

---

### 3. Crear un Pull Request (PR) hacia `develop`

- Desde GitHub: `Compare & Pull Request`
- Explicar qué hiciste, qué archivos modificaste, y si fue probado o no.
- Esperar revisión o aprobación.

---

### 4. Merge a `development`

- Se hace cuando el PR está aprobado y los cambios funcionan correctamente.

---

### 5. Cuando `development` está listo → Merge a `main`

- Esto lo realiza el profe o la persona encargada.
- Sucede cuando se entrega una versión final o estable.

---

## 🧹 Buenas prácticas

- Antes de subir cambios, sincronizá con `development`:
  ```bash
  git checkout development
  git pull origin development
  git checkout feature-tu-nombre
  git merge development
  ```

- No trabajar directamente sobre `main` ni `development`.
- Usar nombres descriptivos en los commits y las ramas.
- Mantener carpetas organizadas (`/hardware`, `/software`, `/docs`).
- Comentar el código y documentar lo importante.

---

## 📄 Plantilla para Pull Request

```markdown
### 🚀 ¿Qué se hizo?
- [x] Implementación de X
- [x] Pruebas iniciales
- [ ] Falta calibración

### 🧪 ¿Cómo se probó?
Se probó con lectura serial y comparación con valores de referencia.

### 📝 Notas
- Falta revisión de compatibilidad con el módulo Y.
```

---

Cualquier duda o mejora sobre el flujo, ¡se charla en equipo! 💬

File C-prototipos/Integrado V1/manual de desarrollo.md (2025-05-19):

## Manual de Desarrollo

### Descripcion
Este programa funcionara como la primer version del modulo integrado para el proyecto del sistema hidroponico, buscando compilar en este todas las pruebas unitarias realizadas previamente por el equipo, y buscando integrar lo realizado en un programa que haga uso de ello de la manera mas eficiente posible, dentro de nuestras capacidades.
Buscaremos mantener un directorio organizado con partes definidas que siendo funcionales, la falta de una no genere errores fatales al momento de la compilacion del mismo

### Estrcutura del Directorio:

- 📦Integrado V1
-  ┣ 📂.pio                                         || Integramos un comando en el .ini para que aqui se guarden los binarios
-  ┃ ┣ 📂build
-  ┃ ┃ ┣ 📂esp32dev
-  ┃ ┗ 📂libdeps
-  ┣ 📂.vscode
-  ┃ ┣ 📜c_cpp_properties.json
-  ┃ ┣ 📜extensions.json
-  ┃ ┗ 📜launch.json
-  ┣ 📂include
-  ┃ ┣ 📜configuracion.h                            || El archivo que gestionara las configuraciones globales
-  ┃ ┗ 📜README
-  ┣ 📂lib
-  ┃ ┗ 📜README
-  ┣ 📂sensor                                       || Se utilizada cada prueba unitaria previa como una libreria
-  ┃ ┣ 📂include                                    || Aca colocamos el archivo .h qu luego es llamado en main
-  ┃ ┣ 📂src                                        || Y aca al .cpp con las funciones y declaraciones definidas para su funcionamiento
-  ┃ ┗ 📜library.json                               || pequeño json que describe la libreria, tags, creadores, etc
-  ┣ 📂src
-  ┃ ┗ 📜main.cpp                                   || Elemento que llamara y coordinara el resto de los elemento
-  ┣ 📂test
-  ┃ ┗ 📜README                                     || Pruebas unitarias del sistema
-  ┣ 📜.gitignore
-  ┣ 📜manual de desarrollo.md                      || Documentacion del programa
-  ┗ 📜platformio.ini                               || inciador del programa. Registra ls librerias utilizadas  

------

### lib
Aqui se crea una carpeta para cada sensor/actuador/elemento.
Se le coloca el nombre, y se copian desde el directorio de pruebas unitarias el 
- .cpp en **src** de la carpeta 
- .h en **include**
- el manual de uso del sensor fuera del src
- Modificar el json con las caractesiticas requeridas

- **EJEMPLO**
  -  📦Buzzer
  -  ┣ 📂include
  -  ┃ ┗ 📜buzzer.h
  -  ┣ 📂src
  -  ┃ ┗ 📜buzzer.cpp
  -  ┣ 📜library.json
  -  ┗ 📜README

------

### Orquestacion
Vamos a crear diferentes elementos que nos permitan la orquestacion del sistema
 - conecciones_manager: Este articulara y gestionara las funciones relacionadas a wifi y gsm. Esto incluye gestion de credenciales, pinuot en caso de falla del gsm, reconecciones y logs de error
 - sensores_manager: articulara las funciones, pinouts, variales y devoluciones de los sensores
 - actuadores_manager: articulara las acciones activas como la bomba, luces y alarmas. Se encargada de adminstrar la respuesta por umbrales, y errores relacionados
 - configuracion.h: configuraciones globales del sistema
 - main.cpp buscaremso mantenerlo reducido, llamando a los manager que se encargaran de ejecutar internamente las orquestaciones de sus respectivos elementos a fin de mantener un procedimiento claro y consiso, facil de leer y dicernir posibles errores

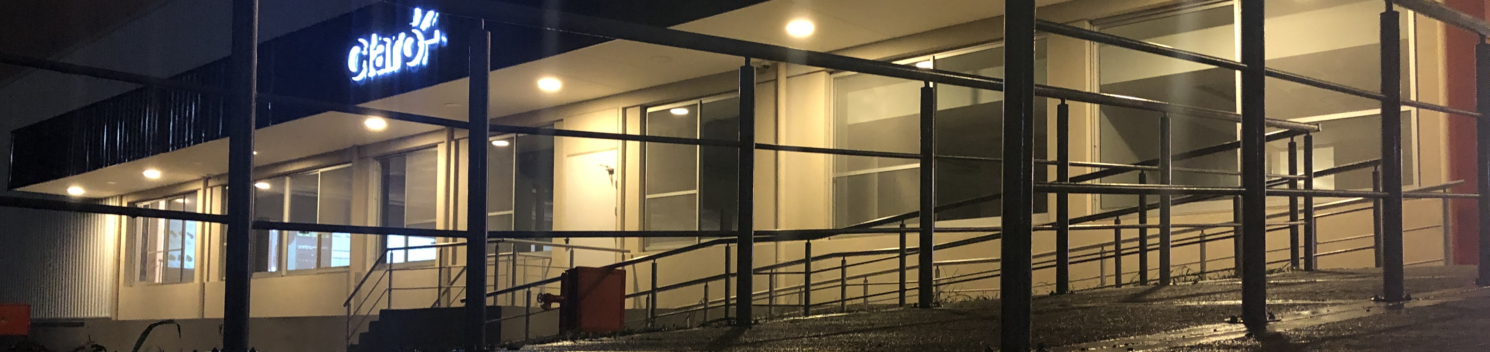
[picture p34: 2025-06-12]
C-prototipos/Pruebas_Unitarias/FRONTEND/build/assets/im10.jpg

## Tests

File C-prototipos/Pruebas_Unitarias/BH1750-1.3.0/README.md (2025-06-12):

# BH1750

<br>

Este paquete contiene una biblioteca de Arduino para placas de ruptura de sensores de luz digitales que contienen el IC BH1750FVI.

La placa BH1750 utiliza I2C para la comunicación, lo que requiere dos pines para comunicarse con el dispositivo. La configuración del bus I2C debe hacerse en el código del usuario (no en el código de la biblioteca). Este enfoque ha sido adoptado para que se pueda realizar una vez y mejorará el soporte para las diversas opciones en diferentes plataformas.

Un módulo común que contiene el componente BH1750 es el GY-30 que se muestra a continuación.

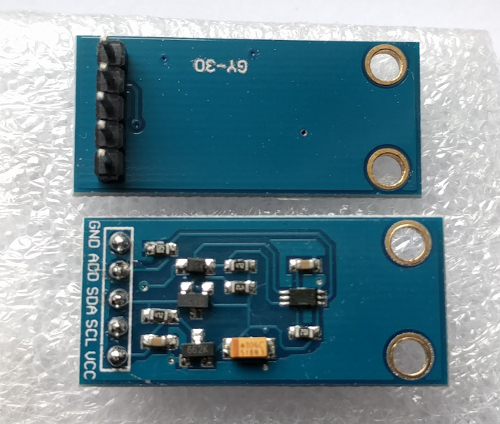
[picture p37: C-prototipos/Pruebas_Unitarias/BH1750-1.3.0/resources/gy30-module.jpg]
GY-30 Module image


## Resumen

El BH1750 tiene seis modos de medición diferentes que se dividen en dos grupos; mediciones continuas y mediciones de una sola vez. En modo continuo, el sensor mide continuamente el valor de la luminosidad. En modo de una sola vez, el sensor realiza solo una medición y luego entra en modo de bajo consumo.

Cada modo tiene tres precisiones diferentes:

- Modo de Baja Resolución - (precisión de 4 lx, tiempo de medición de 16 ms)
- Modo de Alta Resolución - (precisión de 1 lx, tiempo de medición de 120 ms)
- Modo de Alta Resolución 2 - (precisión de 0.5 lx, tiempo de medición de 120 ms)
Por defecto, esta biblioteca utiliza el Modo de Alta Resolución Continua, pero puedes cambiar esto a un modo diferente pasando el argumento de modo a BH1750.begin().

Cuando se utiliza el modo de una sola vez, su sensor entrará en modo de apagado de energía cuando complete la medición y usted la haya leído. Cuando el sensor se vuelva a encender, volverá al modo predeterminado, lo que significa que debe ser reconfigurado nuevamente en modo de una sola vez. 
Esta biblioteca ha sido implementada para reconfigurar automáticamente el sensor cuando intente una medición nuevamente, por lo que no debería preocuparse por esos detalles de bajo nivel.

Normalmente, obtendrá un valor entero que representa el equivalente de lux.
- Modo de baja resolución - (rango genérico: de 0.0 hasta 54612.5 lux)
- Modo de alta resolución - (rango genérico: de 0.0 hasta 54612.5 lux)
- Modo de alta resolución 2 - (rango genérico: de 0.0 hasta 27306.25 lux)

El sensor en sí devuelve un entero sin signo de 16 bits. Por lo tanto, el valor máximo está limitado en general. La conversión estándar entre los llamados 'cuantos' y lux es 1/1.2, lo que significa que obtienes un valor más pequeño. Como usamos flotantes, si ocurre un error recibirás un valor negativo.

 - -1 no se transmitieron datos válidos desde el sensor 
 - -2 el dispositivo no está configurado. De lo contrario, los cuantos medidos se convierten a lux y se devuelven. Si no se cambian los parámetros avanzados, el valor máximo de lux es 54612.5 lx.Como los cuantos del sensor impactan de luz en un marco de tiempo específico, podrías cambiar este marco de tiempo.

  Esto es necesario si usas una ventana de superposición o compensas por influencias ambientales como la oscuridad. 
  Este marco de tiempo es definido por un registro que se llama MTreg. Por lo tanto, podrías elegir un valor entre 32 y 254. El valor predeterminado es 69; ten en cuenta que el tiempo de medición cambia en consecuencia.

La hoja de datos del chip BH1750 se puede obtener
[here](https://www.mouser.de/datasheet/2/348/Rohm_11162017_ROHMS34826-1-1279292.pdf)[2011.11 Rev.D]

## Instalacion 

- **(Para Arduino >= 1.5.x)** Instale este paquete buscándolo en el
Administrador de Bibliotecas de Arduino y luego haciendo clic en ``instalar``. Alternativamente, esta
biblioteca se puede instalar manualmente haciendo clic en "Clonar o descargar" -> botón "Descargar ZIP".
Luego abra el IDE de Arduino, haga clic en `Esquema -> Incluir biblioteca -> Agregar biblioteca .ZIP`
y seleccione el archivo descargado.

- **(Para Arduino < 1.5.x)** Descargue este paquete como un archivo comprimido haciendo clic
en "Clonar o descargar" -> botón "Descargar ZIP". Luego extraiga el archivo en
``<Su Directorio de Usuario>/Mis Documentos/Arduino/libraries/`` y renómbralo
a `BH1750`. Reinicie el IDE.

El siguiente [video](https://youtu.be/ACTMQvPVMLs) de YouTube (específicamente a partir de
las 7:20) proporciona una buena visión general de cómo instalar manualmente esta biblioteca y
cargar un ejemplo utilizando el IDE de Arduino.

BH1750 Video Tutorial (https://youtu.be/ACTMQvPVMLs?t=437)

Información sobre el proceso de instalación de la biblioteca - https://www.arduino.cc/en/Guide/Libraries

## Ejemplo

A continuación se presenta un ejemplo utilizando la biblioteca BH1750 en conjunto con la placa GY-30 (que contiene el componente BH1750). El código de ejemplo utiliza la biblioteca BH1750 en el modo de alta precisión continua por defecto al realizar mediciones de luz.

### CableadoConexiones:
- VCC -> 3V3 o 5V
- GND -> GND
- SCL -> SCL (A5 en Arduino Nano, Uno, Leonardo, etc. o 21 en Mega y Due, en esp8266 seleccionable libremente)
- SDA -> SDA (A4 en Arduino Nano, Uno, Leonardo, etc. o 20 en Mega y Due, en esp8266 seleccionable libremente)
- ADD -> NC/GND o VCC (ver abajo)
El pin ADD se usa para establecer la dirección I2C del sensor. Por defecto (si el voltaje de ADD es menor que 0.7 * VCC) la dirección del sensor será 0x23. Si tiene un voltaje mayor o igual a 0.7VCC (por ejemplo, si lo has conectado a VCC), la dirección del sensor será 0x5C.

La conexión de la placa del sensor GY-30 a un Arduino se muestra en el diagrama a continuación.

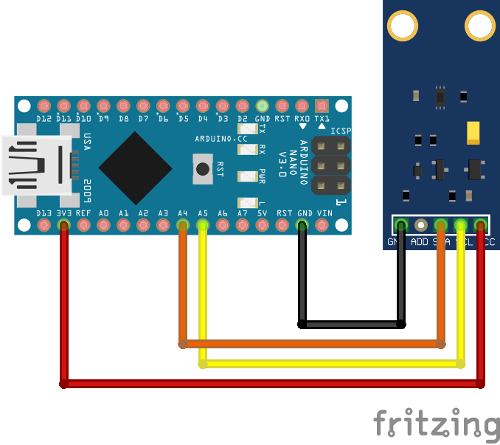
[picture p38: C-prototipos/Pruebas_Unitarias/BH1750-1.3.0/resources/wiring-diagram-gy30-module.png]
Example wiring diagram image


*La imagen de arriba fue creada utilizando [Fritzing](http://fritzing.org/home/) y
el módulo GY-30 fue obtenido de [here](http://omnigatherum.ca/wp/?p=6)*.

### Código

Cargue el código de prueba BH1750 en su Arduino.

``` c++
#include <Wire.h>
#include <BH1750.h>

BH1750 lightMeter;

void setup(){

  Serial.begin(9600);

// Inicializar el bus I2C (la biblioteca BH1750 no lo hace automáticamente) // En dispositivos esp8266 puedes seleccionar los pines SCL y SDA usando Wire.begin(D4, D3);
  Wire.begin();

  lightMeter.begin();
  Serial.println(F("BH1750 Test"));

}

void loop() {

  float lux = lightMeter.readLightLevel();
  Serial.print("Light: ");
  Serial.print(lux);
  Serial.println(" lx");
  delay(1000);

}
```

### Output

Moving the sensor to face more light results in the lux measurements increasing.
```
BH1750 Test
Light: 70.0 lx
Light: 70.0 lx
Light: 59.0 lx
Light: 328.0 lx
Light: 333.0 lx
Light: 335.0 lx
Light: 332.0 lx
```

### Más Ejemplos

El directorio ``examples`` contiene casos de uso más avanzados, como el uso de diferentes modos, direcciones I2C y múltiples instancias de Wire.

## Desarrolladores

La siguiente información es para los desarrolladores de esta biblioteca.

### Formato de Código

El código en este proyecto está formateado utilizando la herramienta ``clang-format``.

Se pueden encontrar buenas instrucciones para instalar ``clang-format``
[here](https://learn.adafruit.com/the-well-automated-arduino-library/formatting-with-clang-format)

Una vez que se haya instalado la herramienta ``clang-format``, puedes ejecutar el script de conveniencia (``ci/code-format.bash``) para verificar o aplicar el formato del código. El script debe ejecutarse desde el directorio raíz del repositorio.

```shell$ ./ci/code-format.bash```Este script también se ejecuta como parte de las comprobaciones de integración continua del proyecto.Si realizas cambios en los archivos de código, entonces el formato del código se puede aplicar simplemente pasando *apply* como argumento al script.

### Análisis de Código

El código en este proyecto se analiza utilizando ``arduino-lint``. La herramienta se puede instalar siguiendo las instrucciones [aquí](https://arduino.github.io/arduino-lint/latest/installation/).

Para ejecutar el analizador en el proyecto, utiliza el siguiente comando.

```shell$ arduino-lint --library-manager update --compliance strict```

El mismo comando se ejecuta como parte de las revisiones de integración continua del proyecto.Si se reportan errores o advertencias, entonces corrígelos y vuelve a ejecutar el script hasta que se resuelvan.

### Construir Localmente

El código en este proyecto se puede construir localmente utilizando la herramienta ``arduino-cli``. La herramienta se puede instalar siguiendo las instrucciones [aquí](https://github.com/arduino/arduino-cli#quickstart). Una vez que tenga la herramienta instalada, puede compilar los scripts de ejemplo utilizando el script de conveniencia (``ci/compile-examples.bash``).
```shell
$ ./ci/compile-examples.bash
```

Este script realiza las mismas acciones que las comprobaciones de compilación de integración continua del proyecto.

### Proceso de Lanzamiento

- Actualiza las cadenas de versión en ``library.json`` y ``library.properties``.
- Crea una nueva versión del proyecto y utiliza el nuevo número de versión como etiqueta. Haz clic en Publicar.
- Ahora espera aproximadamente una hora para que aparezca en el administrador de bibliotecas de Arduino.

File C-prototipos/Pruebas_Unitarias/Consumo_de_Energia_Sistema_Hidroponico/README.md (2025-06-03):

# Consumo de Energía - Sistema Hidropónico

Este proyecto implementa y prueba un **módulo de medición de consumo de energía** para sistemas hidropónicos, utilizando un sensor I2C para obtener voltaje, corriente y calcular potencia. Incluye pruebas unitarias exhaustivas con mocks de hardware para asegurar la robustez del código.

---

## Estructura del Proyecto

```
Consumo_de_Energia_Sistema_Hidroponico/
├── lib/
│   └── Modulo_de_Energia/
│       ├── Modulo_de_Energia.h
│       ├── Modulo_de_Energia.cpp
│       └── library.json
├── src/
│   └── main.cpp
├── test/
│   └── Test_Modulo_de_Energia/
│       ├── test_main.cpp
│       ├── test_cases.cpp
│       ├── Resultados.md
│       └── lib/
│           └── MockWire/
│               ├── Wire.h
│               ├── Wire.cpp
│               └── library.json
├── platformio.ini
└── README.md
```

---

## Descripción de Carpetas y Archivos

### `lib/Modulo_de_Energia/`
- **Modulo_de_Energia.h / .cpp**: Implementación de la clase `Modulo_de_Energia`, que abstrae la lectura de voltaje, corriente y cálculo de potencia desde un sensor I2C.
- **library.json**: Metadatos de la librería para PlatformIO.

### `src/`
- **main.cpp**: Ejemplo de uso en un entorno real (ESP32), mostrando cómo inicializar el módulo y leer valores periódicamente.

### `test/Test_Modulo_de_Energia/`
- **test_main.cpp**: Entrada principal para ejecutar las pruebas unitarias con Unity.
- **test_cases.cpp**: Implementación de todos los casos de prueba, cubriendo inicialización, lecturas correctas, fallos de comunicación, simulaciones de carga y condiciones anómalas.
- **Resultados.md**: Informe de resultados de las pruebas unitarias ejecutadas.
- **lib/MockWire/**: Implementación mock de la librería `Wire` de Arduino para simular el bus I2C en pruebas.
  - **Wire.h / Wire.cpp**: Mock completo de la clase `TwoWire` (Wire), permitiendo simular lecturas, escrituras y errores de comunicación.
  - **library.json**: Metadatos del mock para PlatformIO.

### Raíz del Proyecto
- **platformio.ini**: Configuración de entornos PlatformIO para pruebas (`esp32_test_energia`) y firmware real (`esp32_firmware`).
- **README.md**: Este archivo.

---

## Principales Características

- **Lectura de voltaje y corriente** vía I2C, con conversión a unidades físicas.
- **Cálculo de potencia** en tiempo real.
- **Manejo robusto de errores de comunicación**.
- **Pruebas unitarias exhaustivas** usando Unity y mocks de hardware.
- **Simulación de condiciones reales y anómalas** (baja/alta carga, fallos de sensor).

---

## Ejemplo de Uso (main.cpp)

```cpp
#include <Arduino.h>
#include "Modulo_de_Energia.h"

Modulo_de_Energia energyMonitor(Wire);

void setup() {
  Serial.begin(115200);
  energyMonitor.begin();
  if (energyMonitor.isCommunicationOK()) {
    Serial.println("Módulo de energía inicializado correctamente.");
  }
}

void loop() {
  if (energyMonitor.isCommunicationOK()) {
    float voltage = energyMonitor.getVoltage();
    float current = energyMonitor.getCurrent();
    float power = energyMonitor.getPower();
    Serial.print("Voltaje: "); Serial.println(voltage);
    Serial.print("Corriente: "); Serial.println(current);
    Serial.print("Potencia: "); Serial.println(power);
  }
  delay(5000);
}
```

---

## Pruebas Unitarias

- **Framework:** Unity (integrado con PlatformIO).
- **MockWire:** Simula el bus I2C y el sensor para pruebas determinísticas.
- **Cobertura:** Inicialización, lecturas correctas, fallos de comunicación, simulaciones de carga, condiciones anómalas.
- **Resultados:** Ver `test/Test_Modulo_de_Energia/Resultados.md`.

---

## Cómo Ejecutar

1. **Instalar PlatformIO** en VSCode.
2. **Seleccionar entorno**:  
   - Para pruebas: `esp32_test_energia`
   - Para firmware: `esp32_firmware`
3. **Compilar y ejecutar pruebas**:
   ```
   pio test -e esp32_test_energia
   ```
4. **Subir firmware real**:
   ```
   pio run -e esp32_firmware -t upload
   ```

---

## Créditos

- Autor: Juan Diego Gonzalez Antoniazzi
- Contacto: juandi19972008@gmail.com

---

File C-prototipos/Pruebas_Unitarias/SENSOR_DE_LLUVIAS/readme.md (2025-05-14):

##codigo minnimo para sensor de lluvia analogico:

```cpp

#include <Arduino.h>

const int analogPin = 4;  // Puedes cambiar esto a 5 si prefieres usar ese pin
unsigned long previousMillis = 0;
const unsigned long interval = 500; // Intervalo de lectura en milisegundos

void setup() {
  Serial.begin(9600);  // Inicializa la comunicación serial
  Serial.println("Sensor de agua listo");
}

void loop() {
  unsigned long currentMillis = millis(); // Obtiene el tiempo actual

  if (currentMillis - previousMillis >= interval) {
    previousMillis = currentMillis;  // Actualiza el último tiempo de ejecución

    int sensorValue = analogRead(analogPin); // Lee el valor analógico del sensor

    Serial.print("Nivel de agua: ");
    Serial.println(sensorValue); // Imprime el valor en el monitor serial

    if (sensorValue > 700) {  // Si el nivel de agua supera el umbral
      Serial.println("¡Agua detectada!");
    } else {
      Serial.println("No hay agua.");
    }
  }
}

``

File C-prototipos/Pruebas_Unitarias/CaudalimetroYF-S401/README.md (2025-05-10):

## Pruebas de lectura del sensor de flujo YF-S401

* Este código lee el sensor de flujo YF-S401 y calcula la tasa de flujo en litros por minuto.
* El sensor de flujo YF-S401 genera un pulso por cada 7.5 ml de agua que pasa a través de él.
* El código utiliza una interrupción para contar los pulsos generados por el sensor y calcula la tasa de flujo cada segundo.
* El resultado se imprime en el monitor serial.

* Simulación online en wokwi: https://wokwi.com/projects/430498455168999425

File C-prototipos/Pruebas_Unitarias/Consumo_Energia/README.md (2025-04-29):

# Presentación del Proyecto: Consumo de Energía en Sistema Hidropónico

Este proyecto utiliza un ESP32-S3 DevKitM-1 para medir el consumo de energía en un sistema hidropónico. Está desarrollado con el framework Arduino y configurado para ser utilizado con PlatformIO.

## Estructura del Proyecto

### Archivos Principales
- **`platformio.ini`**: Archivo de configuración principal de PlatformIO que define el entorno de desarrollo para la placa ESP32-S3 y el framework Arduino.
- **`wokwi.toml`**: Configuración para el simulador Wokwi, especificando el firmware y el archivo ELF generados.
- **`diagram.json`**: Representación del diseño del circuito en el simulador Wokwi, incluyendo un ESP32 y un potenciómetro.
- **`.gitignore`**: Lista de archivos y carpetas ignorados por Git, como `.pio` y `.vscode`.

### Código Fuente
- **`src/main.cpp`**: Contiene el código principal que realiza lecturas analógicas del pin 36 para calcular corriente y voltaje, imprimiendo los resultados en el monitor serial.

### Carpetas
- **`include/`**: Archivos de cabecera del proyecto.  
  - `README`: Explica cómo usar archivos de cabecera en C/C++.
- **`lib/`**: Bibliotecas específicas del proyecto.  
  - `README`: Describe cómo organizar y usar bibliotecas privadas en PlatformIO.
- **`test/`**: Pruebas unitarias del proyecto.  
  - `README`: Explica cómo ejecutar pruebas unitarias con PlatformIO.
- **`.vscode/`**: Configuración para Visual Studio Code.  
  - `c_cpp_properties.json`: Configuración de rutas de inclusión y compilador.  
  - `launch.json`: Configuración para depuración.  
  - `extensions.json`: Recomendaciones de extensiones.

### Otros Archivos
- **`.pio/`**: Carpeta generada automáticamente que contiene archivos de compilación como el firmware (`firmware.bin`) y el ELF (`firmware.elf`).
- **`project.checksum`**: Archivo generado automáticamente con un hash del proyecto.

## Requisitos
- **Hardware**: ESP32-S3 DevKitM-1.  
- **Software**:  
  - PlatformIO IDE (recomendado con Visual Studio Code).  
  - Simulador Wokwi (opcional para pruebas virtuales).

## Configuración y Ejecución
1. Clona el repositorio en tu máquina local.
2. Abre el proyecto en Visual Studio Code con la extensión de PlatformIO instalada.
3. Conecta el ESP32-S3 DevKitM-1 a tu computadora.
4. Compila y sube el firmware al ESP32 ejecutando:
   ```bash
   pio run --target upload
   ```
5. Abre el monitor serial para visualizar los datos:
   ```bash
   pio device monitor
   ```

## Ejecución de Pruebas Unitarias

Para ejecutar las pruebas unitarias del proyecto, sigue los pasos a continuación:

1. Asegúrate de que el sensor esté conectado al pin especificado en el código (`36`).
2. Abre una terminal en la raíz del proyecto.
3. Ejecuta el siguiente comando para compilar y ejecutar las pruebas:
   ```bash
      pio test -e esp32-s3-devkitm-1
      ```
   4. Observa los resultados en el monitor serial. Si el sensor no está presente, se notificará la falla en la consola.

## Simulación en [Wokwi](https://wokwi.com/projects/429326475435077633)
1. Abre el archivo `diagram.json` en el simulador Wokwi.
2. Verifica que el firmware esté configurado correctamente en `wokwi.toml`.

## Documentación Adicional
- [PlatformIO Documentation](https://docs.platformio.org/)
- [Wokwi Simulator](https://wokwi.com/)
- [Arduino Framework](https://www.arduino.cc/)

## Autor
Juan Diego Gonzalez Antoniazzi
```

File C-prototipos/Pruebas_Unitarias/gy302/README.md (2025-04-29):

# Proyecto_hidroponico<p align="center">
  ISPC Hydroponics logo
</p>

<h1 align="center">ISPC Hydroponics</h1>

<p align="center">
  🌱 Cultivando el futuro con tecnología inteligente 💧
</p>

---

## 📌 Descripción

**ISPC Hydroponics** es un proyecto IoT colaborativo desarrollado por estudiantes del Instituto Superior Politecnico Cordoba, correspondientes a la materia Proyecto Integrador 2 de la Tecnicatura Superior en Telecomunicaciones.
En el mismo se busca aplicar tecnología para monitorear y automatizar un sistema de cultivo hidropónico. 
El objetivo es construir una solución inteligente, ecológica y accesible que combine sensores, microcontroladores y visualización en tiempo real.

---

## 📂 Organización

```
📁 /Requisitos         → los requisitos del proyecto  
📁 /Investigacion      → Archivos de investigacion, procedimientos, apuntes, datasheets 
📁 /Prototipos         → Prototipos, pruebas unitarios, integraciones, etc 
📁 /Presentacion       → Documentacion de presentacion, videos, diapositivas, manuales de uso
📁 /assets       → Imágenes, logo, multimedia  
📄 README.md     → Este archivo  
📄 LICENSE       → Licencia del proyecto
```

# Manual de Usuario: GY-302 (BH1750) con ESP32 en PlatformIO

##  📌 Requisitos
- **Hardware**:
  - Placa ESP32
  - Sensor GY-302 (BH1750)
  - Conexiones I2C (cables dupont)

- **Software**:
  - PlatformIO (extensión en VSCode)  

## 🔧 Instalación
1. **Estructura del proyecto**:
   ```bash
   /lib
     /GY302_BH1750
       GY302_BH1750.h
       GY302_BH1750.cpp
   /src
     main.cpp
   platformio.ini
---

##  Configuración crítica en platformio.ini:  
```ini  
[env:esp32dev]
platform = espressif32
board = esp32dev
framework = arduino
monitor_speed = 9600
lib_deps = claws/BH1750@^1.3.0
build_flags = -I${PROJECT_DIR}/lib/GY302_BH1750  
```    

## 📦 Librería Personalizada

### GY302_BH1750.h
```cpp

#ifndef GY302_BH1750_H
#define GY302_BH1750_H

#include <BH1750.h>

class GY302 {
  public:
    bool begin();
    float readLightLevel();
  private:
    BH1750 lightMeter;
};
#endif

```

### GY302_BH1750.cpp

```cpp  

#include "GY302_BH1750.h"
#include <Wire.h>

bool GY302::begin() {
  Wire.begin();
  return lightMeter.begin(BH1750::CONTINUOUS_HIGH_RES_MODE);
}

float GY302::readLightLevel() {
  return lightMeter.readLightLevel();
} 

```   

##  🔌 Conexiones Físicas

| **Sensor GY-302** | **ESP32** |
|---|---|
| VCC (rojo) | 3.3V (alimentación) |
| GND (negro) | GND |
| SDA (azul) | GPIO21 |
| SCL (verde) | GPIO22 |

##  💻 Código de Ejemplo (main.cpp)

```cpp

#include <Arduino.h>
#include <GY302_BH1750.h>

GY302 sensor;
const int LED_PIN = 2; // LED interno

void setup() {
  Serial.begin(9600);
  pinMode(LED_PIN, OUTPUT);
  
  if (!sensor.begin()) {
    Serial.println("¡Error en sensor!");
    while (1);
  }
}

void loop() {
  digitalWrite(LED_PIN, HIGH);
  float lux = sensor.readLightLevel();
  Serial.print("Luz: ");
  Serial.print(lux);
  Serial.println(" lx");
  delay(100);
  digitalWrite(LED_PIN, LOW);
  delay(9900); // Total 10 segundos
}

```   

## 🛠 Solución de Problemas

### Errores Comunes y Soluciones

| **Error** | **Causa Probable** | **Solución** |
|---|---|---|
| `GY302_BH1750.h: No such file` | Ruta incorrecta del header | Verificar: <br>- `build_flags = -I${PROJECT_DIR}/lib/GY302_BH1750` en `platformio.ini` <br>- El archivo debe estar en `/lib/GY302_BH1750/` |
| `undefined reference to GY302::...` | El `.cpp` no se compila | Mover `GY302_BH1750.cpp` a `/lib/GY302_BH1750/` (no dentro de `src/`) |
| Valores incorrectos (ej: "kx") | Error tipográfico en `Serial.print()` | Revisar: <br>```cpp <br>Serial.println(" lx"); // Debe ser 'lx' (lux) <br>``` |
| Sensor no detectado | Problemas de conexión I2C | Verificar: <br>- Cableado (SDA=GPIO21, SCL=GPIO22) <br>- Alimentación (3.3V) |
| Lecturas inconsistentes | Ruido eléctrico o luz ambiental | Promediar múltiples lecturas: <br>```cpp <br>lux = (sensor.read() + sensor.read()) / 2; <br>``` |

### Pasos para Debugging Avanzado

1. **Verificar conexiones I2C**:
   ```cpp
   void setup() {
     Wire.begin();
     Serial.begin(9600);
     while (!Serial);
     Wire.beginTransmission(0x23); // Dirección del BH1750
     if (Wire.endTransmission() == 0) {
       Serial.println("Sensor detectado!");
     } else {
       Serial.println("Error: Revisar conexiones");
     }
   }  
    ```

---

## 📄 Licencia

Distribuido bajo la Licencia Creative Commons.

---

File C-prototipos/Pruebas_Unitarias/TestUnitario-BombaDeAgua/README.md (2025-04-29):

# 🚿 Proyecto: Control de Bomba de Agua con ESP32 vía WiFi

---

## 📋 Descripción general

Este proyecto permite **encender** y **apagar** una **bomba de agua de 5V** de forma remota mediante una **página web** servida desde un **ESP32**.\
También muestra el **estado actual** (encendida o apagada) utilizando **LEDs indicadores**.

El ESP32 crea un **servidor web** que puede ser accedido desde cualquier dispositivo conectado a la **misma red WiFi**.

---

## ⚙️ Componentes utilizados

| Componente | Descripción |
| --- | --- |
| ESP32 Dev Module | Microcontrolador WiFi |
| Relé de 5V | Controla la bomba de agua |
| Bomba de agua 5V | Actuador principal |
| LED Verde | Indica "Bomba Encendida"  |
| LED Rojo | Indica "Bomba Apagada" |
| Resistencias (220Ω) | Para los LEDs |
| Cables de conexión  | |

---

## 🧹 Organización del Código

El proyecto está organizado en los siguientes archivos:

| Archivo | Propósito |
| --- | --- |
| `main.cpp` | Inicializa el ESP32, configura pines, conecta WiFi e inicia el servidor. |
| `webserver.cpp`  | Define las rutas web (`/`, `/encender`, `/apagar`) y genera la página web. |
| `my_webserver.h` | Declara constantes, pines y funciones relacionadas con el servidor. |

---

## 🛠️ Instalación y Uso

1. **Modificar credenciales WiFi** en `main.cpp`:
   ```cpp
   WiFi.begin("TU_SSID", "TU_PASSWORD");
   ```
2. **Subir el código** al ESP32 mediante PlatformIO o Arduino IDE.
3. **Conectar la bomba** de agua a través del módulo relé.
4. **Abrir el Monitor Serie** y tomar nota de la **IP asignada** al ESP32.
5. **Ingresar esa IP** desde cualquier navegador web conectado a la misma red.
6. **Controlar la bomba** usando los botones "ENCENDER" y "APAGAR".

---

## 🌐 Funcionamiento del servidor web

- Al ingresar a la página, verás dos botones:

  - **ENCENDER**: Activa la bomba, enciende LED verde.
  - **APAGAR**: Desactiva la bomba, enciende LED rojo.

- El servidor utiliza rutas:

  - `/` → Página principal con los botones.
  - `/encender` → Activa el relé y el LED verde.
  - `/apagar` → Desactiva el relé y enciende el LED rojo.

---

---

## 🔌 Diagrama de conexiones

| ESP32 Pin | Conexión | Descripción |
| --- | --- | --- |
| 27 | IN del módulo Relé | Controla el estado del relé |
| 25 | Ánodo LED Verde (con resistencia 220Ω)  | Indica bomba encendida |
| 26 | Ánodo LED Rojo (con resistencia 220Ω) | Indica bomba apagada |
| GND | GND Relé y GND LEDs | Tierra común |
| 5V | VCC Relé (opcional si el relé es de 5V) | Alimentación |

- El relé cierra o abre el circuito de la bomba, permitiendo su encendido o apagado.
- Los LEDs informan visualmente el estado actual.

---

## 📜 Código fuente resumido

### `main.cpp`

```cpp
void setup() {
  Serial.begin(115200);
  pinMode(RELAY_PIN, OUTPUT);
  pinMode(LED_VERDE, OUTPUT);
  pinMode(LED_ROJO, OUTPUT);

  digitalWrite(RELAY_PIN, LOW);
  digitalWrite(LED_VERDE, LOW);
  digitalWrite(LED_ROJO, HIGH);

  WiFi.begin("TU_SSID", "TU_PASSWORD");
  while (WiFi.status() != WL_CONNECTED) { delay(1000); }
  setupWebServer();
}

void loop() {
  server.handleClient();
}
```

### `webserver.cpp`

```cpp
server.on("/", HTTP_GET, []() {
  server.send(200, "text/html", "<html>...</html>");
});

server.on("/encender", HTTP_POST, []() {
  digitalWrite(RELAY_PIN, HIGH);
  digitalWrite(LED_VERDE, HIGH);
  digitalWrite(LED_ROJO, LOW);
  server.sendHeader("Location", "/");
  server.send(303);
});

server.on("/apagar", HTTP_POST, []() {
  digitalWrite(RELAY_PIN, LOW);
  digitalWrite(LED_VERDE, LOW);
  digitalWrite(LED_ROJO, HIGH);
  server.sendHeader("Location", "/");
  server.send(303);
});
```

### `my_webserver.h`

```cpp
#define RELAY_PIN 27
#define LED_VERDE 25
#define LED_ROJO 26

extern WebServer server;
void setupWebServer();
```

---

## ⚡ Recomendaciones

- Verificar las conexiones del relé (IN, GND, VCC).
- Asegurar que la bomba no sobrepase la capacidad del relé.
- Usar fuentes de alimentación separadas si se maneja carga alta.
- Tener precaución al trabajar con agua cerca de dispositivos electrónicos.

---

## 👨‍💻 Alumno del ISPC

Proyecto realizado NicolasB-27&#x20;

---

---

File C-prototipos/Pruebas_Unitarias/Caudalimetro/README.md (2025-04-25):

## Caudalímetro de efecto Hall YF-S201 o YF-S401
### ¿Qué es un caudalímetro?
Un caudalímetro es un sensor que mide el caudal de un líquido, o sea, cuánto fluido pasa por él por unidad de tiempo. Se expresa generalmente en litros por minuto (L/min).

### ¿Cómo funciona un caudalímetro de efecto Hall?
1. **Turbina interna:** Dentro del caudalímetro hay una pequeña hélice o turbina que gira cuando el agua fluye a través del sensor.

2. **Sensor de efecto Hall:** Al lado de la hélice hay un imán y un sensor Hall. Cada vez que el imán pasa frente al sensor, se genera un pulso digital.

3. **Salida digital:** El caudalímetro emite una señal cuadrada (ON/OFF) en un pin de salida (normalmente 5V o 3.3V). Esta señal se conecta a un pin digital de tu microcontrolador.

4. **Medición:** El microcontrolador cuenta cuántos pulsos llegan por segundo, y a partir de eso calcula el caudal.

### Ejemplo
Supongamos que un modelo te da esta fórmula:
```
Caudal (L/min) = (Pulsos por segundo) / 7.5
```

Entonces, si en un segundo contás 75 pulsos, el caudal sería:
```
75 / 7.5 = 10 L/min
```

### Proyecto en Wokwi
https://wokwi.com/projects/429039351948338177

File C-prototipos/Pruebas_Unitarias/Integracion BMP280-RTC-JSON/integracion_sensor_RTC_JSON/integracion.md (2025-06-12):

# 🎯 Integracion sensor, RTC con Salida JSON
En esta integracion se propone un programa que:

- Inicializa el BMP280 y el RTC.  
- Pide la hora actual.  
- Lee presión, temperatura y calcula altura.  
- Crea un JSON con los datos obtenidos.  
- Imprime el JSON formateado.
- Envia el JSON por MQTT  

# Clase Jsonificadora
Se trata de una clase que permita crear archivos JSON de diferente longitud de acuerdo a la necesidad

## La clase debería:

- Poder recibir distintas mediciones (timestamp, temperatura, presión, altura, etc).

- No agregar al JSON los valores que estén "vacíos" o "no válidos" o que decidamos no transmitir. (A desarrollar)

- Permitir armar el JSON limpio sin basura o nulos innecesarios, con funciones que solo agregan si el dato es válido. (A desarrollar)  
  
## Estrategia para "solo valores nuevos"
### Dos opciones:

a) Comparar con última medición:
Solo jsonificamos si el valor cambió respecto a la última vez.

b) Flags de "cambio":
Cada sensor podría tener un bool changed que activa si hubo un cambio significativo.

Ejemplo simple:

```cpp
if (abs(nuevaTemperatura - ultimaTemperatura) > umbral) {
    // agregar temperatura al JSON
}
```  
  
# Clase JsonBuilder  

## Descripción  

La clase JsonBuilder permite construir mensajes JSON de manera fácil y ordenada, pensada especialmente para proyectos embebidos (como ESP32, Arduino, etc.).
Ideal para preparar mensajes que luego se envíen por protocolos como MQTT o HTTP.

### Dependencias
```bash
pio lib install "bblanchon/ArduinoJson"  
```  

## Métodos Disponibles  
| Método | Descripcion |
|---|---|
| JsonBuilder() | Constructor. Inicializa el objeto y limpia el documento JSON interno. |
| void limpiar() | Limpia completamente el contenido actual del JSON. Se debe usar para comenzar un nuevo documento. |
| void agregarCampo(const char* nombre, String valor) | |
| void agregarCampo(const char* nombre, float valor) | Agrega un campo al documento JSON. |
| void agregarCampo(const char* nombre, int valor) | |  
| String construir() | Construye el JSON en formato texto bonito (formato "pretty") y lo devuelve como String. |  

nombre: Nombre que tendrá el campo en el JSON.

valor: Valor a almacenar. Puede ser un String, un float o un int.

Nota: Si el valor tipo String está vacío, no se agregará el campo.

## Ejemplo de Uso Básico
```cpp

#include "JsonBuilder.h"

JsonBuilder creadorJSON;

void setup() {
  Serial.begin(115200);

  creadorJSON.limpiar();
  creadorJSON.agregarCampo("temperatura_C", 24.7);
  creadorJSON.agregarCampo("presion_hPa", 1015.2);
  creadorJSON.agregarCampo("mensaje", "Todo en orden");

  String jsonGenerado = creadorJSON.construir();

  Serial.println("📦 JSON:");
  Serial.println(jsonGenerado);
}

void loop() {
  // No hacemos nada aquí
}  
```  

### Salida esperada:
```json
{
  "temperatura_C": 24.7,
  "presion_hPa": 1015.2,
  "mensaje": "Todo en orden"
}  
```  

## Recomendaciones
- Usar limpiar() antes de construir un nuevo JSON para evitar incluir datos anteriores.

- No saturar el documento con demasiados datos: el tamaño del StaticJsonDocument es fijo (512 bytes por defecto).

- Para campos que no siempre estén disponibles (por ejemplo, sensores desconectados), no llamar a agregarCampo o enviar un String vacío para omitirlos.

# Clase SensorDataMQTT
📂 Archivos involucrados  
SensorDataMQTT.h: declaración de la clase y su interfaz pública.  

SensorDataMQTT.cpp: definición de los métodos de la clase.  

## 📌 Objetivo general
La clase SensorDataMQTT encapsula:

- la conexión WiFi con IP estática,  
- la conexión con un broker MQTT usando la librería PubSubClient,  
- la publicación de un mensaje (en formato JSON) a un topic MQTT.  

Permite un uso limpio desde el main.cpp o setup()/loop() del programa, sin tener que ensuciar el flujo principal con detalles de red.

## 📤 ¿Qué hace exactamente?  
**Métodos públicos (public:)**  
## `SensorDataMQTT(...)`  
Constructor: inicializa la clase con parámetros de red (WiFi y MQTT), y guarda una instancia única (singleton).  

**Parámetros:**

`ssid, password`: credenciales de WiFi.

`broker, port`: datos del broker MQTT.

`ip, gateway, subnet`: configuración de IP estática.

## `void conectarWiFi()`  
Configura y conecta a la red WiFi con IP fija.

`WiFi.config(...)`: fija la IP, gateway, subnet y DNS.

`WiFi.begin(...)`: inicia la conexión.

Espera a que `WiFi.status()` sea `WL_CONNECTED`.

Muestra la IP obtenida por consola.

⚠️ DNS estática fija a 8.8.8.8 (Google DNS).

## `void conectarMQTT()`
Conecta con el broker MQTT.

Usa `client.setServer(...)` para definir IP/hostname y puerto del broker.

Intenta conectar con `client.connect(...)` bajo el nombre ESP32_bmp280.

Reintenta cada 2 segundos si falla.

⚠️ El ID "ESP32_bmp280" es fijo y hardcoded → podría ser configurable o dinámico si se conecta más de un ESP32 al mismo broker.

## `void manejarMQTT()`
Mantiene la conexión activa y llama a client.loop().

Verifica si la conexión MQTT está caída (!client.connected()).

Si es así, vuelve a llamar a conectarMQTT().

Luego, ejecuta `client.loop()` para procesar eventos del cliente.

💡 Se debe llamar en cada ciclo del loop() principal para mantener la conexión viva y recibir mensajes (aunque acá no hay subscripciones activas).

## `void publicarLecturas(String cadena_JSON)`
Publica un mensaje JSON (o cualquier String) al topic "sensores/datos".

Convierte el String a un char[] para usarlo en `client.publish(...)`.

El JSON viene como parámetro externo, y no lo construye internamente.

### Variables privadas (private:)
```cpp
const char* ssid;
const char* password;
const char* broker;
int port;
IPAddress ip, gateway, subnet;
WiFiClient espClient;
PubSubClient client;  
```
Estas variables almacenan:

- credenciales de red,

- configuración de IP fija,

- broker MQTT y puerto,

- los objetos base para comunicación: WiFiClient y PubSubClient.

- Singleton (por si se usa callback en el futuro)
```cpp
static SensorDataMQTT* instancia;  
```  

La clase guarda una instancia estática de sí misma, para manejar callbacks de MQTT a futuro.

Esto se usa en el patrón de "callback wrapper", ya que la función que recibe mensajes en PubSubClient debe ser static.

Aunque actualmente está comentado:

```cpp
//void procesarMensaje(char* topic, byte* payload, unsigned int length);
//static void callbackWrapper(char* topic, byte* payload, unsigned int length);  
```
Y en el .cpp:

```cpp
/*void SensorDataMQTT::callbackWrapper(...) {
   if (instancia) {
       instancia->procesarMensaje(...);
   }
}*/  
```  

💡 Esto permite que una función global (requerida por la lib MQTT) redirija el mensaje a un método de instancia real.

🛠️ Posibles mejoras
ID de cliente MQTT dinámico o configurable.

Callbacks MQTT: recibir y procesar mensajes desde el broker.

Reconnect exponential backoff: evitar reconectar cada 2s linealmente.

Configuración modular externa (por ejemplo desde config.h o SPIFFS).

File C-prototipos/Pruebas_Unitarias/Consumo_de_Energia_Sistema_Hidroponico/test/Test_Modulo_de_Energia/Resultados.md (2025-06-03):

# Informe de Pruebas Unitarias: Módulo Consumo de Energía

**Fecha:** 2025-06-02
**Entorno:** `esp32_test_energia` (PlatformIO)

## Resumen General

| Total Pruebas | Pasadas ✅ | Falladas ❌ | Ignoradas ➖ |
|---|---|---|---|
| 18 | 18 | 0 | 0 |

**Estado General: TODAS LAS PRUEBAS PASARON** 🎉

## Detalles de las Pruebas Ejecutadas

| Nombre de la Prueba | Estado | Duración (ms) |
|---|---|---|
| test_module_initialization_ok | PASSED | ~7 |
| test_module_initialization_fail | PASSED | ~5 |
| test_voltage_reading_nominal | PASSED | ~7 |
| test_voltage_reading_scaled | PASSED | ~8 |
| test_current_reading_nominal | PASSED | ~8 |
| test_current_reading_scaled | PASSED | ~7 |
| test_power_calculation_nominal | PASSED | ~8 |
| test_power_calculation_zero_values | PASSED | ~10 |
| test_read_failure_voltage_tx | PASSED | ~5 |
| test_read_failure_voltage_req | PASSED | ~6 |
| test_read_failure_current_tx | PASSED | ~7 |
| test_read_failure_current_req | PASSED | ~8 |
| test_power_after_read_failure | PASSED | ~12 |
| test_low_load_simulation | PASSED | ~8 |
| test_medium_load_simulation | PASSED | ~9 |
| test_high_load_simulation | PASSED | ~11 |
| test_anomalous_low_v_high_i | PASSED | ~9 |
| test_anomalous_high_v_low_i | PASSED | ~10 |

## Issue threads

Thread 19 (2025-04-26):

GY-302 Módulo Sensor de Luz digital BH1750

pleroldan, 2025-04-26:

pleroldan, 2025-04-26:
El BH1750 entrega la intensidad luminosa directamente en unidades Lux (Lx). El lux es la unidad derivada del S.I. de Unidades para la iluminancia o nivel de iluminación. Equivale a un lumen /m². Se usa en la fotometría como medida de la luminancia, tomando en cuenta las diferentes longitudes de onda según la función de luminosidad, un modelo estándar de la sensibilidad a la luz del ojo humano.

Ejemplos de iluminación (Lux):

    Noche: 0.001-0.02
    Luz de medianoche: 0.02-0.3
    Interior nublado: 5-50
    Exterior nublado: 50-500
    Soleado Interior: 100-1000
    Bajo el sol de verano: alrededor de 10^6
    Recomendado para lectura de libros: 50-60;
    Estándar de video casero: 1400.

Closed 2025-05-06.

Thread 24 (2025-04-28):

Sensor Calidad del Agua TDS

MacarenaAC, 2025-04-28:
**Modulo Sensor de Calidad de Agua Analogico TDS (Solidos Disueltos Totales) con Sonda**

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

Un medidor de TDS mide la cantidad total de sólidos disueltos como sales, minerales y metales en el agua. A medida que aumenta la cantidad de sólidos disueltos en el agua, aumenta la conductividad del agua y eso nos permite calcular los sólidos disueltos totales en ppm (mg/L).
Si bien calcular los sólidos disueltos total son un buen indicador para monitorear la calidad del agua, hay que tener en cuenta que no mide los contaminantes en el agua. Por lo tanto, NO se debe utilizar únicamente en este indicador para determinar si el agua es apta para el consumo o no.
Un medidor de TDS puede ser útil para monitorear la calidad del agua en muchas aplicaciones como piscinas, acuarios, peceras, hidroponía, purificadores de agua, etc.

Especificaciones Modulo:
- Voltaje de entrada: 3.3V a 5V DC
- Voltaje de salida: 0V a 2.3V DC
- Corriente de trabajo: 3 a 6mA
- Salida: Analogica
- Rango de medicion de TDS: 0 ~ 1000 ppm
- Precision de medicion TDS: ± 10% F.S. (25°C)
- Interfaz del modulo: XH2.54-3P
- Interfaz de electrodo: XH2.54-2P
- Conectores: VCC, GND, Data (Analogica)

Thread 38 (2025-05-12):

PLANTILLA ISSUE

vittoriodurigutti, 2025-05-12:
**PLANTILLA ISSUE**
[resumen del issue]

---

**Descripción**
- Prueba Unitaria | Documentacion | Base de Datos | Software(frontend/backend)
  Descripción concisa del problema o funcionalidad solicitada.
- **Comportamiento esperado**
  ¿Cuál debería ser el resultado en condiciones ideales?
- **Comportamiento observado**
  Resultado de la prueba en formato .md o imagen

---

**Pasos para reproducir**
1. Encender dispositivo y conectarse a la red
2. Ejecutar X comando / llamar al endpoint Y
3. Observar Z

---

**Finalizacion**
Cerrar con comentario describiendo el cierre, resultado o detalles de la ubicacion del elemento en cuestion

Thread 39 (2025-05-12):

Documentar Variables de Medicion

vittoriodurigutti, 2025-05-12:
### Documentar Variables de Medicion
Documentar las variables finales a medir en el proyecto

---
**Descripcion**:
- realizar un tablero utilizando node red conectado remotamente a la/s API predispuestas por el profesor, a fin de reflejar en tiempo real los KPI y metricas del proyecto

**Comportamiento esperado**

- [ ] el/los dashboards realizados con sus respectivos links de acceso
- [ ] documentacion del uso/configuracion de los mismos

**Comportamiento observado**
  Resultado de la prueba en formato .md o imagen

---

**Finalizacion**
Cerrar con comentario describiendo el cierre, resultado o detalles de la ubicacion del elemento en cuestion

lucianoilujan, 2025-05-13:
verificar

Closed 2025-05-13.

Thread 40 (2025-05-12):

Actualizacion de Documentacion Presente en Proyecto

vittoriodurigutti, 2025-05-12:
### Actualizacion de Documentacion Presente en Proyecto
Verificar la documentacion actual en el proyecto y optimizar si posible

---
**Descripcion**:
- verificar la el readme principal, datasheets de los elementos a utilizar, agregar en caso de faltar alguno  de los anteriores, optimizar dentro de lo posible la legibilidad de la documentacion.
- crear subdirectorios/carpetas para mejorar el orden de lo ya presentado
-  docuementar lo ordenado para poder tener una vista mas clara del proyecto

- **Comportamiento esperado**
una visualizacion mejor definida de lo realizado al momento, listado en un readme o en los comentarios del issue indicado los directorio con las rutas relativas (ej: /c prototipo/pruebas unitarias/..)

- **Comportamiento observado**
  Resultado de la prueba en formato .md o imagen

---

**Finalizacion**
Cerrar con comentario describiendo el cierre, resultado o detalles de la ubicacion del elemento en cuestion

MacarenaAC, 2025-06-18:
Se agrega documentacion en investigacion, como datasheet faltantes e informacion de protocolos de comunicacion. Ademas en la carpeta presentacion se integra un manual de usuario, poster del proyecto y el proyecto ABP.

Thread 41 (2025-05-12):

Dashboard con NodeRed

vittoriodurigutti, 2025-05-12:
### Documentar Variables de Medicion
Documentar las variables finales a medir en el proyecto

---
**Descripcion**:
- realizar un tablero utilizando node red conectado remotamente a la/s API predispuestas por el profesor, a fin de reflejar en tiempo real los KPI y metricas del proyecto

**Comportamiento esperado**

- [ ] el/los dashboards realizados con sus respectivos links de acceso
- [ ] documentacion del uso/configuracion de los mismos

**Comportamiento observado**
  Resultado de la prueba en formato .md o imagen

---

**Finalizacion**
Cerrar con comentario describiendo el cierre, resultado o detalles de la ubicacion del elemento en cuestion

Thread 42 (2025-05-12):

Dashboards con Grafana

vittoriodurigutti, 2025-05-12:
### Dashboards con Grafana
Realizar un tablero utilizando Grafana, que refleje las lecturas y resultado del proyecto

---
**Descripcion**:
- realizar un tablero utilizando grafana conectado remotamente a la/s API predispuestas por el profesor, a fin de reflejar en tiempo real los KPI y metricas del proyecto

**Comportamiento esperado**

- [ ] el/los dashboards realizados con sus respectivos links de acceso
- [ ] documentacion del uso/configuracion de los mismos

**Comportamiento observado**
  Resultado de la prueba en formato .md o imagen

---

**Finalizacion**
Cerrar con comentario describiendo el cierre, resultado o detalles de la ubicacion del elemento en cuestion

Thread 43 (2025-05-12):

Definir estructura de base de datos

vittoriodurigutti, 2025-05-12:
### Definir estructura de base de datos
- Base de Datos a Utlizar:  MariaDB

---
**Descripcion**:
- diseñar la estructura de la base de datos relacional, mediante un esquema de entidad-relacion de forman que refleje las variables a medir, identificacion de los dispositivios, timestamps, boolenos para aquellos elementos que se definen como ON/OFF, y otras consideraciones que se consideren al momento del diseño.

**Comportamiento esperado**

- [ ] Esquema legible con la arquitectura de la BD esperada
- [ ] [extra] idealmente proponiendo/definiendo las PK y FK para reducir la llevada a punto

**Comportamiento observado**
  Resultado de la prueba en formato .md o imagen

---

**Finalizacion**
Cerrar con comentario describiendo el cierre, resultado o detalles de la ubicacion del elemento en cuestion

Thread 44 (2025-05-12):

Definir comunicación MQTT

vittoriodurigutti, 2025-05-12:
### Definir comunicación MQTT
Documentar las configuraciones posibles para la comuincacion MQTT entre los dispositivos con las API, y el panel externo

---
**Descripcion**:
- Hay que definir la configuracion de la comunicacion. Esto implica tomar el broker brindado por el profe y documentarlo en algun apartado del proyecto.
- definir los (posible) topics indicando la finalizad de cada uno. (ej info de los sesnores, info actuadores,)
- documentar esto de forma legible para poder extrapolarlo facilmente a la configuracionfinal

**Comportamiento esperado**

- [ ] Documento formato .md indicando claramente el broker, los topics y la finalidad de estos.

**Comportamiento observado**
  Resultado de la prueba en formato .md o imagen

---

**Finalizacion**
Cerrar con comentario describiendo el cierre, resultado o detalles de la ubicacion del elemento en cuestion

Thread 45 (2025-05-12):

Revisar y adaptar sensores (impresion 3D)

vittoriodurigutti, 2025-05-12:
### Revisar y adaptar sensores (impresion 3D)
Realizar las adaptacion, y diseño para la ubicacion de los sensores y elementos relacionados al proyecto dentro de cada torre.

---
**Descripcion**:
- adaptar el diseño del prototipo según sea necesario. A fin de poder ubicar eficientemente cada elemento del proyecto (sesnores/actuadores/energia/cables)

**Comportamiento esperado**

- [ ] documentacion con IMG de lo planificado
- [ ] documentos para realizar la impresion correspondiente.

**Comportamiento observado**
  Resultado de la prueba en formato .md o imagen

---

**Finalizacion**
Cerrar con comentario describiendo el cierre, resultado o detalles de la ubicacion del elemento en cuestion

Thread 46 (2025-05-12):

Pruebas Unitarias: Buzzer

vittoriodurigutti, 2025-05-12:
### Pruebas Unitarias: Buzzer
Realizar prueba unitaria para el sensor/actuador: Buzzer

---
**Descripcion**:
- una prueba unitaria en el directorio --/C prototipo/prueba unitaria/buzzer/... en platformio, a fin de incorporar al prototipo integrado.

**Comportamiento esperado**

- [ ] distribucion del codigo del sensor modulado (.h y .cpp) e instaciado (fuciones instancias para ser llamadas en main)
- [ ] documentacion con explicacion del codigo, y consideraciones de uso en el main
- [ ] (preferible )documentacion demostrando su funcionamiento en fisico o simulado

**Comportamiento observado**
  Resultado de la prueba en formato .md o imagen

---

**Finalizacion**
Cerrar con comentario describiendo el cierre, resultado o detalles de la ubicacion del elemento en cuestion

vittoriodurigutti, 2025-05-13:
Se realizan pruebas del buzzer.
Directorio de pruebas: C-prototipos/Pruebas_Unitarias/buzzer
Se documenta funciamiento e incorporacion del mismo al main.
Se realiza prueba en fisico con resultados esperados: logrados

Closed 2025-05-13.

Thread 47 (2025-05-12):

Prueba Unitaria: DHT11

vittoriodurigutti, 2025-05-12:
### Pruebas Unitarias: DHT11
Realizar prueba unitaria para el sensor/actuador: DHT11
---
**Descripción**

una prueba unitaria en el directorio --/C prototipo/prueba unitaria/dht11/... en PlatformIO, a fin de incorporar al prototipo integrado.

**Comportamiento esperado**
- [x]  distribución del código del sensor modulado (.h y .cpp) e instanciado (funciones instanciadas para ser llamadas en main).
- [x]  documentación con explicación del código y consideraciones de uso en main.
- [x]  (preferible) documentación demostrando su funcionamiento en físico o simulado.

**Comportamiento observado**

Resultado de la prueba en formato .md o imagen.
---
**Finalización**
Cerrar con comentario describiendo el cierre, resultado o detalles de la ubicación del elemento en cuestión.

Closed 2025-05-14.

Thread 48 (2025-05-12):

Pruebas Unitarias: LRD − GY-302

vittoriodurigutti, 2025-05-12:
### Pruebas Unitarias: LRD − GY-302
Realizar prueba unitaria para el sensor/actuador: LRD − GY-302
---
**Descripción**

una prueba unitaria en el directorio --/C prototipo/prueba unitaria/lrd-gy302/... en PlatformIO.

**Comportamiento esperado**

- [ ]  módulo de sensor (.h/.cpp) con función de lectura de luz calibrada.
- [ ]  documentación de registro de valores lux y umbral de cambio.
- [ ]  (preferible) prueba en simulado de variación lumínica.

**Comportamiento observado**
Resultado de la prueba en formato .md o imagen.
---
**Finalización**
Cerrar con comentario describiendo el cierre, resultado o detalles de la ubicación del elemento en cuestión.

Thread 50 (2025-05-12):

Pruebas Unitarias: BME280

vittoriodurigutti, 2025-05-12:
### Pruebas Unitarias: BME280
Realizar prueba unitaria para el sensor/actuador: BME280

---

**Descripción**

una prueba unitaria en el directorio --/C prototipo/prueba unitaria/bme280/... en PlatformIO.

**Comportamiento esperado**

- [ ]  módulo con funciones de lectura de temperatura, presión y humedad.
- [ ]  documentación de compensación y uso de I²C.
- [ ]  (preferible) simulación de cambios de presión y temperatura.

**Comportamiento observado**
Resultado de la prueba en formato .md o imagen.

---

**Finalización**
Cerrar con comentario describiendo el cierre, resultado o detalles de la ubicación del elemento en cuestión.

Closed 2025-05-15.

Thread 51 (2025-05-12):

Pruebas Unitarias: Sensor TDS

vittoriodurigutti, 2025-05-12:
### Pruebas Unitarias: Sensor TDS
Realizar prueba unitaria para el sensor/actuador: Sensor TDS

---

**Descripción**

una prueba unitaria en el directorio --/C prototipo/prueba unitaria/tds/... en PlatformIO.

**Comportamiento esperado**

 módulo con lectura de conductividad y conversión a ppm.

 documentación sobre calibración y rango de medida.

 (preferible) simulación de concentración de sólidos disueltos.

**Comportamiento observado**

Resultado de la prueba en formato .md o imagen.
---

**Finalización**
Cerrar con comentario describiendo el cierre, resultado o detalles de la ubicación del elemento en cuestión.

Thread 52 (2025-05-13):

Pruebas Unitarias: DS18B20

vittoriodurigutti, 2025-05-13:
### Pruebas Unitarias: DS18B20
Realizar prueba unitaria para el sensor/actuador: DS18B20

---

**Descripción**
una prueba unitaria en el directorio --/C prototipo/prueba unitaria/ds18b20/... en PlatformIO.

**Comportamiento esperado**

- [ ]  módulo con lectura de temperatura 1-wire.
- [ ]  documentación sobre detección de dispositivo y resolución.
- [ ]  (preferible) simulación de cambio térmico.

**Comportamiento observado**
Resultado de la prueba en formato .md o imagen.

---

**Finalización**
Cerrar con comentario describiendo el cierre, resultado o detalles de la ubicación del elemento en cuestión.

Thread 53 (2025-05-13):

Pruebas Unitarias: Flotante Mecánico + Ultrasonido

vittoriodurigutti, 2025-05-13:
### Pruebas Unitarias: Flotante Mecánico + Ultrasonido
Realizar prueba unitaria para el sensor/actuador: Flotante mecánico y ultrasonido

---

**Descripción**
una prueba unitaria en el directorio --/C prototipo/prueba unitaria/flotante-ultrasonido/... en PlatformIO.

**Comportamiento esperado**

- [ ]  módulo del flotante con detección de nivel (ON/OFF).
- [ ]  módulo HC-SR04 con función de distancia en cm.
- [ ]  documentación combinada y casos de margen mínimo/máximo.

**Comportamiento observado**
Resultado de la prueba en formato .md o imagen.

---

**Finalización**
Cerrar con comentario describiendo el cierre, resultado o detalles de la ubicación del elemento en cuestión.

Closed 2025-05-13.

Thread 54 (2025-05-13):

Pruebas Unitarias: Módulo Relay 5V + Bomba de Agua 5V

vittoriodurigutti, 2025-05-13:
### Pruebas Unitarias: Módulo Relay 5V + Bomba de Agua 5V
Realizar prueba unitaria para el sensor/actuador: Relay + bomba de agua 5V

---

**Descripción**
una prueba unitaria en el directorio --/C prototipo/prueba unitaria/relay-bomba-5v/... en PlatformIO.

**Comportamiento esperado**

- [ ]  módulo relay con activación/desactivación de bomba.
- [ ]  documentación de tiempos de switching y aislamiento.
- [ ]  (preferible) simulación de arranque/parada de bomba.

**Comportamiento observado**
Resultado de la prueba en formato .md o imagen.

---

**Finalización**
Cerrar con comentario describiendo el cierre, resultado o detalles de la ubicación del elemento en cuestión.

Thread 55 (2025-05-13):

Pruebas Unitarias: Sensor de Lluvia

vittoriodurigutti, 2025-05-13:
### Pruebas Unitarias: Sensor de Lluvia
Realizar prueba unitaria para el sensor/actuador: Sensor de lluvia

---

**Descripción**
una prueba unitaria en el directorio --/C prototipo/prueba unitaria/sensor-lluvia/... en PlatformIO.

**Comportamiento esperado**

- [ ]  módulo con lectura analógica/señal digital de humedad.
- [ ]  documentación de umbral de detección y limpieza de datos.
- [ ]  (preferible) simulación de gotas variables.

**Comportamiento observado**
Resultado de la prueba en formato .md o imagen.

---

**Finalización**
Cerrar con comentario describiendo el cierre, resultado o detalles de la ubicación del elemento en cuestión.

pleroldan, 2025-05-23:
Se prueba el sensor en físico. Se sube código correspondiente, se agrega bloque en readme de la carpeta correspondiente

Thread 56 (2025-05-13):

Pruebas Unitarias: Sensor de Gas

vittoriodurigutti, 2025-05-13:
### Pruebas Unitarias: Sensor de Gas
Realizar prueba unitaria para el sensor/actuador: Sensor de gas

---

**Descripción**
una prueba unitaria en el directorio --/C prototipo/prueba unitaria/sensor-gas/... en PlatformIO.

**Comportamiento esperado**

- [ ]  módulo con lectura de concentración de gas (CO, LPG, etc.).
- [ ]  documentación de curva de respuesta y tiempos de calentamiento.
- [ ]  (preferible) simulación de diferentes compuestos.

**Comportamiento observado**
Resultado de la prueba en formato .md o imagen.

---

**Finalización**
Cerrar con comentario describiendo el cierre, resultado o detalles de la ubicación del elemento en cuestión.

Closed 2025-05-14.

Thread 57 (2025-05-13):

Pruebas Unitarias: DS3231

vittoriodurigutti, 2025-05-13:
### Pruebas Unitarias: DS3231
Realizar prueba unitaria para el sensor/actuador: DS3231

---

**Descripción**
una prueba unitaria en el directorio --/C prototipo/prueba unitaria/ds3231/... en PlatformIO.

**Comportamiento esperado**

- [ ]  módulo con lectura/escritura de fecha/hora en RTC.
- [ ]  documentación de formatos y persistencia tras reinicio.
- [ ]  (preferible) simulación de pérdidas de energía y restauración.

**Comportamiento observado**
Resultado de la prueba en formato .md o imagen.

---

**Finalización**
Cerrar con comentario describiendo el cierre, resultado o detalles de la ubicación del elemento en cuestión.

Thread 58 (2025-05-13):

Pruebas Unitarias: Pantalla LCD 20×4 I2C

vittoriodurigutti, 2025-05-13:
### Pruebas Unitarias: Pantalla LCD 20×4 I2C
Realizar prueba unitaria para el sensor/actuador: LCD 20×4 I2C

---

**Descripción**
una prueba unitaria en el directorio --/C prototipo/prueba unitaria/lcd-20x4-i2c/... en PlatformIO.

**Comportamiento esperado**

- [ ]  módulo con inicialización y escritura de líneas.
- [ ]  documentación de direcciones I2C y control de contraste/backlight.
- [ ]  (preferible) simulación de desplazamientos y refrescos.

**Comportamiento observado**
Resultado de la prueba en formato .md o imagen.

---

**Finalización**
Cerrar con comentario describiendo el cierre, resultado o detalles de la ubicación del elemento en cuestión.

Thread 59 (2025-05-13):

Pruebas Unitarias: Módulo Consumo de Energía

vittoriodurigutti, 2025-05-13:
### Pruebas Unitarias: Módulo Consumo de Energía
Realizar prueba unitaria para el sensor/actuador: Módulo consumo de energía

---

**Descripción**
una prueba unitaria en el directorio --/C prototipo/prueba unitaria/consumo-energia/... en PlatformIO.

**Comportamiento esperado**

- [ ]  módulo con lectura de voltaje, corriente y cálculo de potencia.
- [ ]  documentación de escalas de medida y comunicaciones (I2C/SPI).
- [ ]  (preferible) simulación de diferentes cargas.

**Comportamiento observado**
Resultado de la prueba en formato .md o imagen.

---

**Finalización**
Cerrar con comentario describiendo el cierre, resultado o detalles de la ubicación del elemento en cuestión.

Closed 2025-06-03.

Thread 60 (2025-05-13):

Pruebas Unitarias: Módulo Estado de Alimentación / Batería

vittoriodurigutti, 2025-05-13:
### Pruebas Unitarias: Módulo Estado de Alimentación / Batería
Realizar prueba unitaria para el sensor/actuador: Módulo estado alimentación/batería

---

**Descripción**
una prueba unitaria en el directorio --/C prototipo/prueba unitaria/estado-alimentacion-bateria/... en PlatformIO.

**Comportamiento esperado**

- [ ]  módulo con lectura de nivel de batería y detección de corte.
- [ ]  documentación de umbrales de baja tensión y filtros.
- [ ]  (preferible) simulación de descarga progresiva.

**Comportamiento observado**
Resultado de la prueba en formato .md o imagen.

---

**Finalización**
Cerrar con comentario describiendo el cierre, resultado o detalles de la ubicación del elemento en cuestión.

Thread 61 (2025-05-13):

Creacion de Prototipo Completo V1

vittoriodurigutti, 2025-05-13:
### Creacion de Prototipo Completo V1
Creacion de modulo integrado (V1) utilizando las pruebas unitarias decada componenete, asi como incorporar los mecanismos de comunicacion (wifi/bluetooth/mqtt)

---
**Descripcion**:
realizar modulo integrado (V1) en directorio ../C prototipo/integrado_v1/...

**Comportamiento esperado**

- [ ] tomar los elemetos desarrollados en cada prueba unitaria
- [ ] desarrollar los elemtos, configuraciones y codigo para las direferntes comunicaciones
- [ ] documentar el modulo realizado + flujo de datos
- [ ] (preferible) realizar desarrollo del prototipo en fisico

**Comportamiento observado**
  Resultado de la prueba en formato .md o imagen

---

**Finalizacion**
Cerrar con comentario describiendo el cierre, resultado o detalles de la ubicacion del elemento en cuestion

vittoriodurigutti, 2025-05-19:
Se crea directorio bajo nombre: "integrador V1".
Se crea documentacion de desarrollo y manuales de uso
Se define una estrcutura bajo la nocion de librerias de platformio
Se agregan dos ejemplos testeados: Buzzer y HC-SR04
Se definen posibles programas orqustadores (en desarrollo)

vittoriodurigutti, 2025-05-19:
Se crean las librerias para conexion wifi y GSM. Se busco hacerlas no bloqueantes, aunque bloquean al momento solicitar credenciales. Por lo que solo generan inconveniente al momento de iniciar una primera vez. Se gestion en millis, con maquina de estado, gestion y guardado de credecnaiels por preferences. Sujtas a mejoras.

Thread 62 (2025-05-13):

Configuracion de la base de datos

vittoriodurigutti, 2025-05-13:
### Configuracion de la base de datos
A partir del diagrama entidad relacion creado prevaiamente acceder a la base de datos MariaBD, utilizando SGBD de preferencia, y diagramar via queries la entidades y respectivas propiedades-

---
**Descripcion**:
- A partir del diagrama entidad relacion creado prevaiamente acceder a la base de datos MariaBD, utilizando SGBD de preferencia, y diagramar via queries la entidades y respectivas propiedades. Estableces las PK y FK

**Comportamiento esperado**

- [ ] Creacion de la base de datos, entidades, y configuraciones de cada propuedad
- [ ] documentacion del uso/configuracion de los mismos
- [ ] realizar pruebas de registro de datos mediante la utilizacion de [postman] o herramienta similar

**Comportamiento observado**
  Resultado de la prueba en formato .md o imagen

---

**Finalizacion**
Cerrar con comentario describiendo el cierre, resultado o detalles de la ubicacion del elemento en cuestion

Closed 2025-06-16.

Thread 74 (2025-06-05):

Integracion de base de datos a dashboards

diegote7, 2025-06-05:
**Descripción**
Integrar la base de datos Hidroponia (MariaDB) con las herramientas de visualización Grafana y de automatización Node-RED. Esta integración permitirá el monitoreo y control del sistema de cultivo hidropónico en tiempo real.

---

**Objetivos**

- [ ]  Establecer conexión de lectura y escritura entre Node-RED y MariaDB
- [ ]  Configurar flujo de inserción de datos desde sensores (simulados o reales) hacia la tabla sensores
- [ ]  Añadir MariaDB como fuente de datos en Grafana
- [ ]  Crear paneles de visualización en Grafana para temperatura, humedad, pH y EC
- [ ]  Verificar integridad y actualización en tiempo real de los datos

---

**Finalizacion**

- Cerrar con comentario describiendo el cierre o la resolucion de prueba

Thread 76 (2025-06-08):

Crear Documentamentar Visualizaciones en Grafana

diegote7, 2025-06-08:
Crear documento técnico que describa y justifique cada visualización desarrollada en el dashboard de Grafana para el sistema hidropónia.

---

Comportamiento esperado
Documento que incluya:

Propósito de cada tabla utilizada (sistemas, sensores, lecturas, actuadores, eventos de control, umbrales).

Descripción de cada panel (tabla, gráfica, stat, etc.).

Justificación de su uso y cómo contribuye al monitoreo del sistema.

Frase de apoyo para presentación o exposición.

Organización clara por secciones y numeración.

Orientado a presentación oral y documentación del proyecto.

---

Comportamiento observado
Documento generado a partir de definiciones dispersas y comentarios verbales. Falta consolidar en un solo archivo explicativo.

---

Finalización
Cerrar esta issue una vez el archivo justificacion_visualizaciones.md esté en el repositorio con un comentario que indique su ubicación y si se usó en presentación/documentación del proyecto.

Closed 2025-06-08.

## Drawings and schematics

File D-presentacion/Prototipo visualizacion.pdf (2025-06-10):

# HIDROPONIA VERTICAL

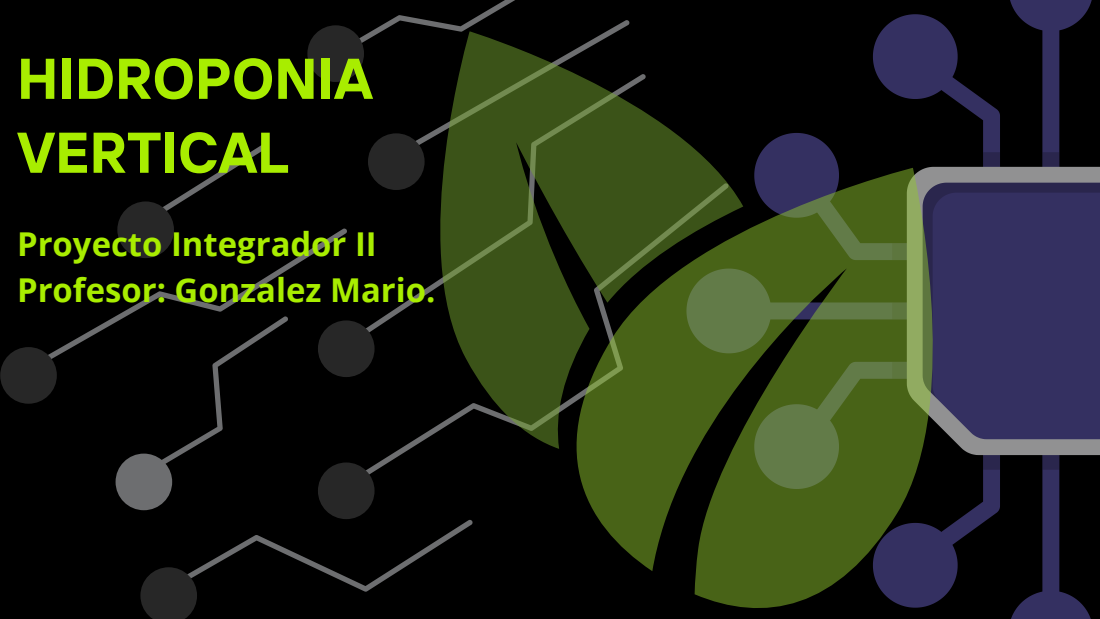
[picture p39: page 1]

Proyecto Integrador II
Profesor: Gonzalez Mario.

# INTRODUCCION

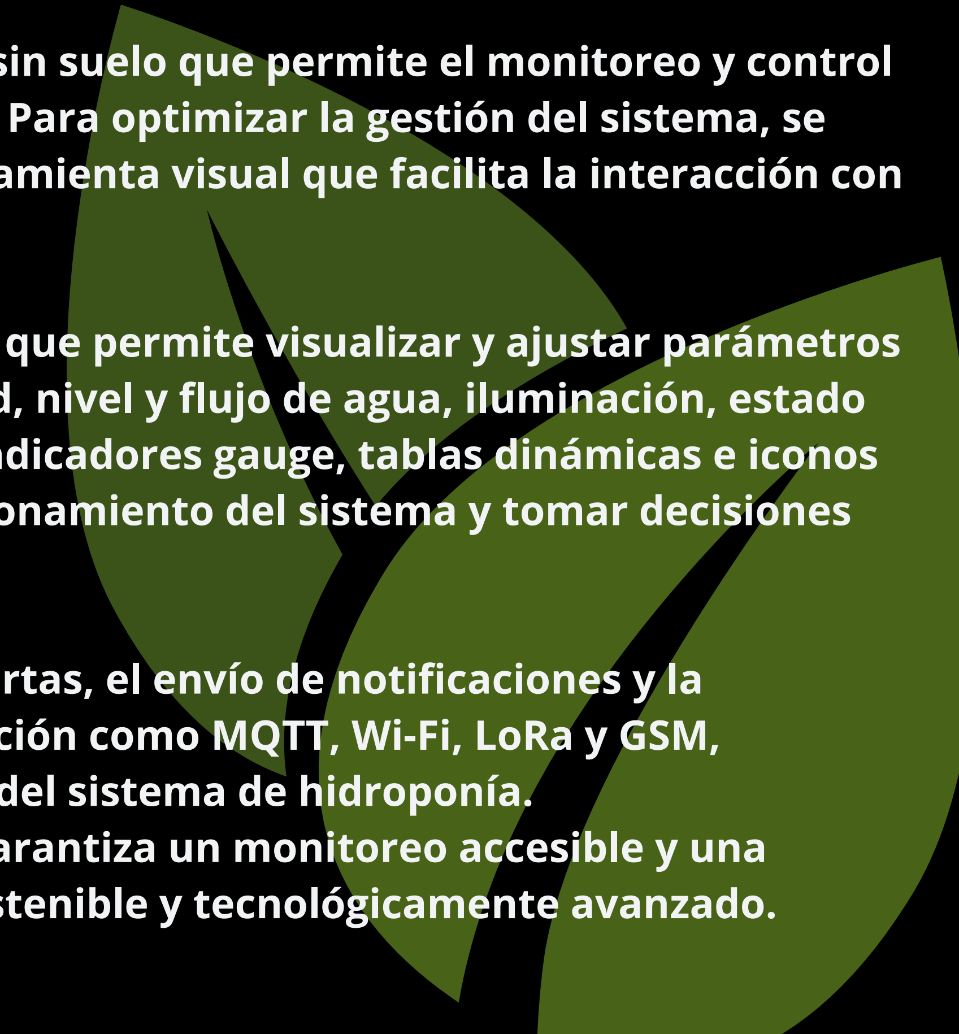
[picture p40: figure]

La hidroponía es un sistema innovador de cultivo sin suelo que permite el monitoreo y control preciso de las condiciones ambientales y del agua. Para optimizar la gestión del sistema, se implementa un dashboard en Node-RED, una herramienta visual que facilita la interacción con los datos en tiempo real.

Este dashboard proporciona una interfaz intuitiva que permite visualizar y ajustar parámetros clave, como temperatura del agua y aire, humedad, nivel y flujo de agua, iluminación, estado de sensores y conectividad. A través de gráficos, indicadores gauge, tablas dinámicas e iconos de estado, los usuarios pueden supervisar el funcionamiento del sistema y tomar decisiones informadas.

Además, el tablero permite la configuración de alertas, el envío de notificaciones y la

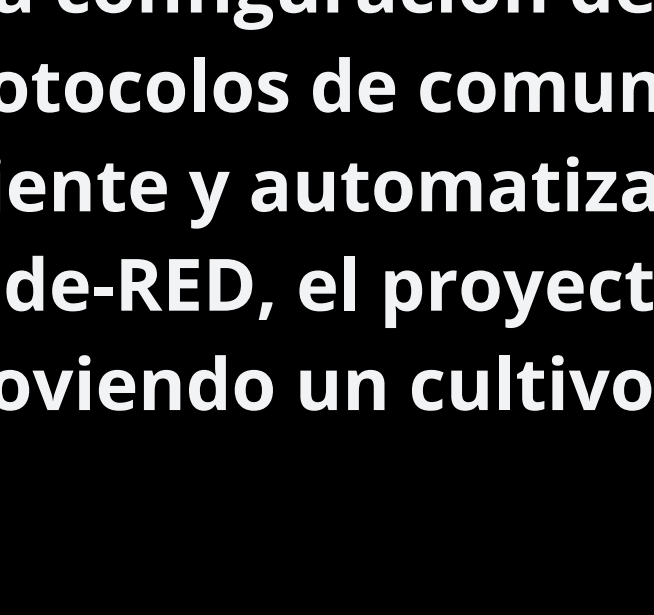
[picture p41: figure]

integración con múltiples protocolos de comunicación como MQTT, Wi-Fi, LoRa y GSM, asegurando una gestión eficiente y automatizada del sistema de hidroponía.
Con esta presentación en Node-RED, el proyecto garantiza un monitoreo accesible y una operación optimizada, promoviendo un cultivo sostenible y tecnológicamente avanzado.

# MONITOREO EN TIEMPO REAL

## Variables en vivo desde MQTT

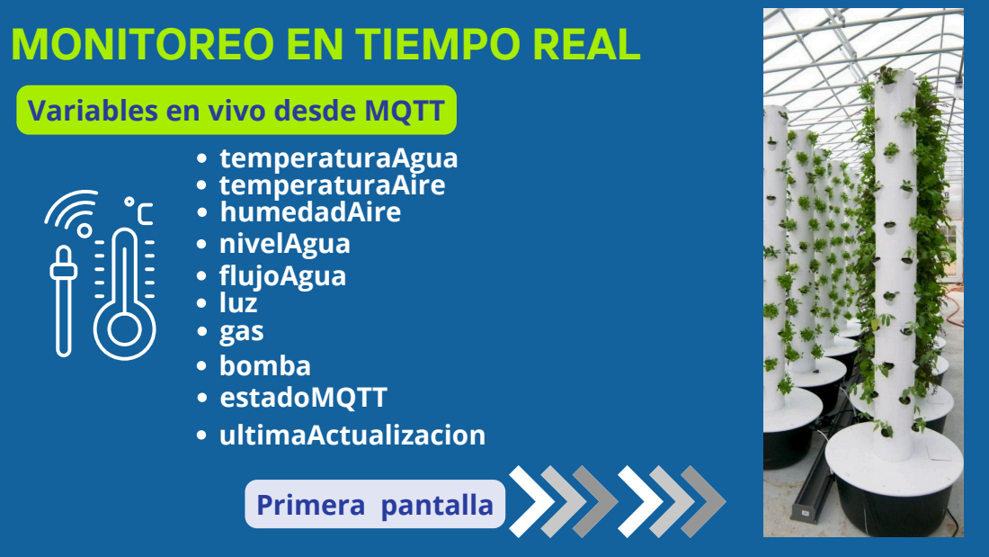
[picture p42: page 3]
temperaturaAgua temperaturaAire humedadAire nivelAgua flujoAgua luz gas bomba estadoMQTT ultimaActualizacion; Primera pantalla

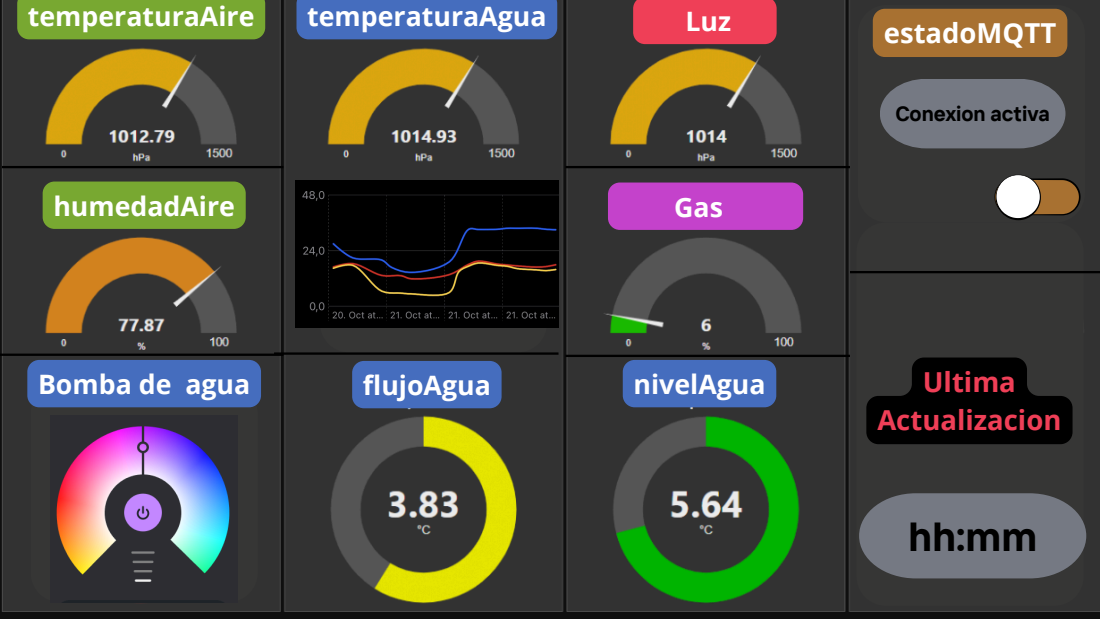
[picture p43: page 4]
Conexion activa; temperaturaAire; temperaturaAgua; humedadAire; flujoAgua; nivelAgua; Luz; Gas; estadoMQTT; Ultima Actualizacion

Bomba de agua

*Segunda opcion de graficos.

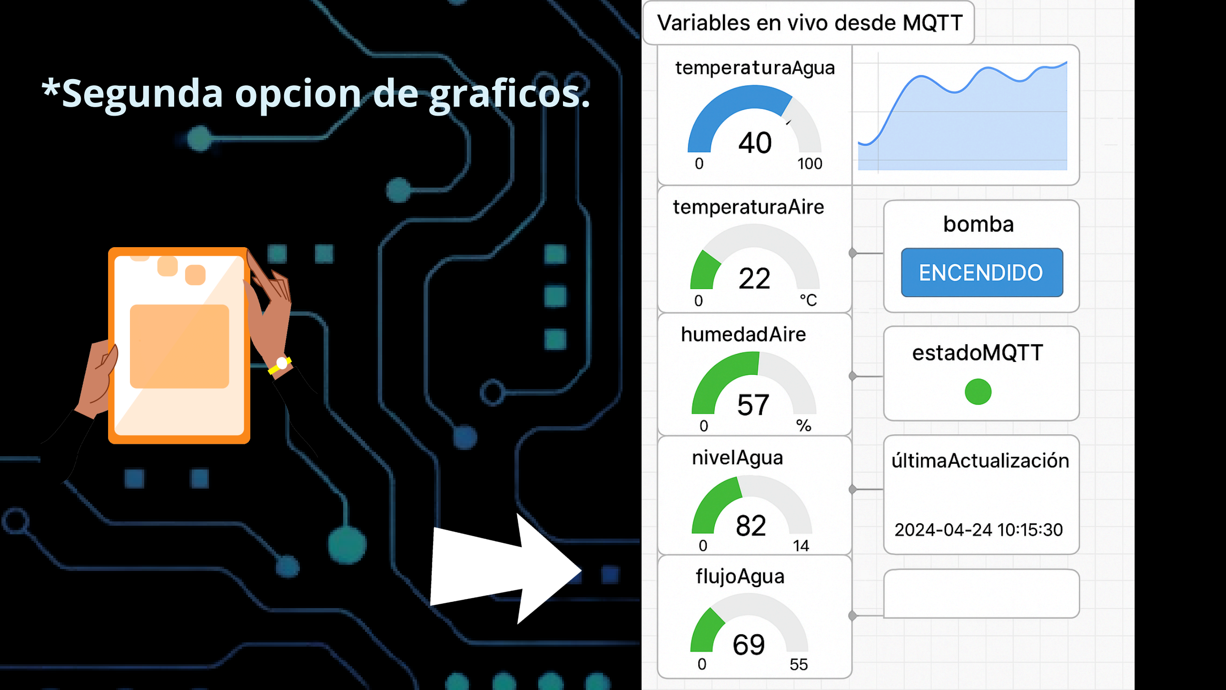
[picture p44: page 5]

# HISTORIAL DE DATOS

## Variables almacenadas en MariaDB

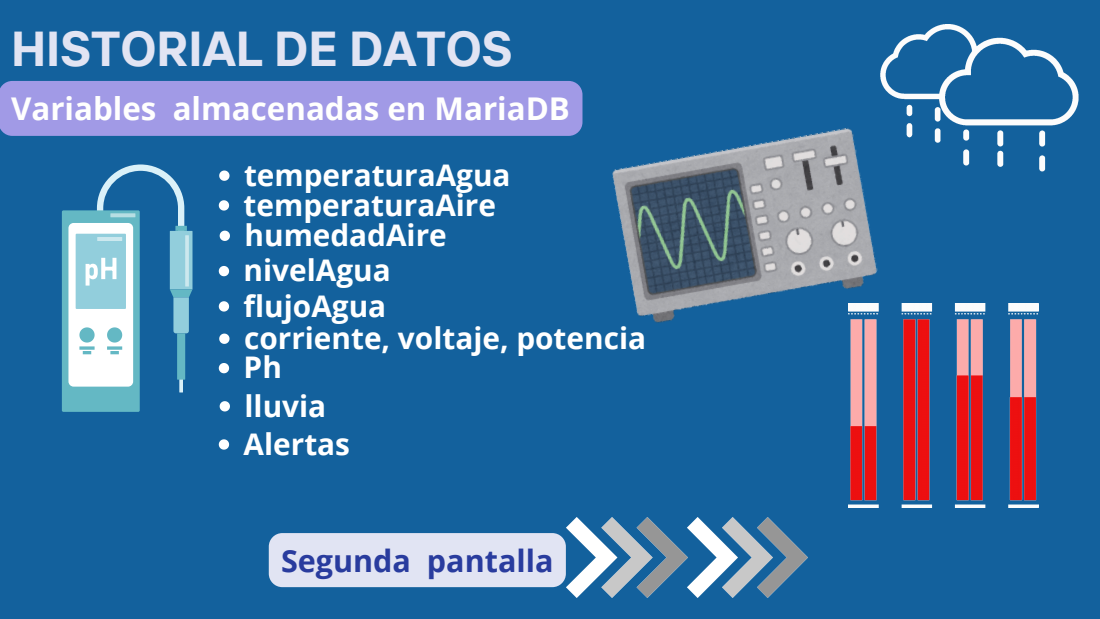
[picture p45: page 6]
temperaturaAgua temperaturaAire humedadAire nivelAgua flujoAgua corriente, voltaje, potencia Ph lluvia Alertas; Segunda pantalla

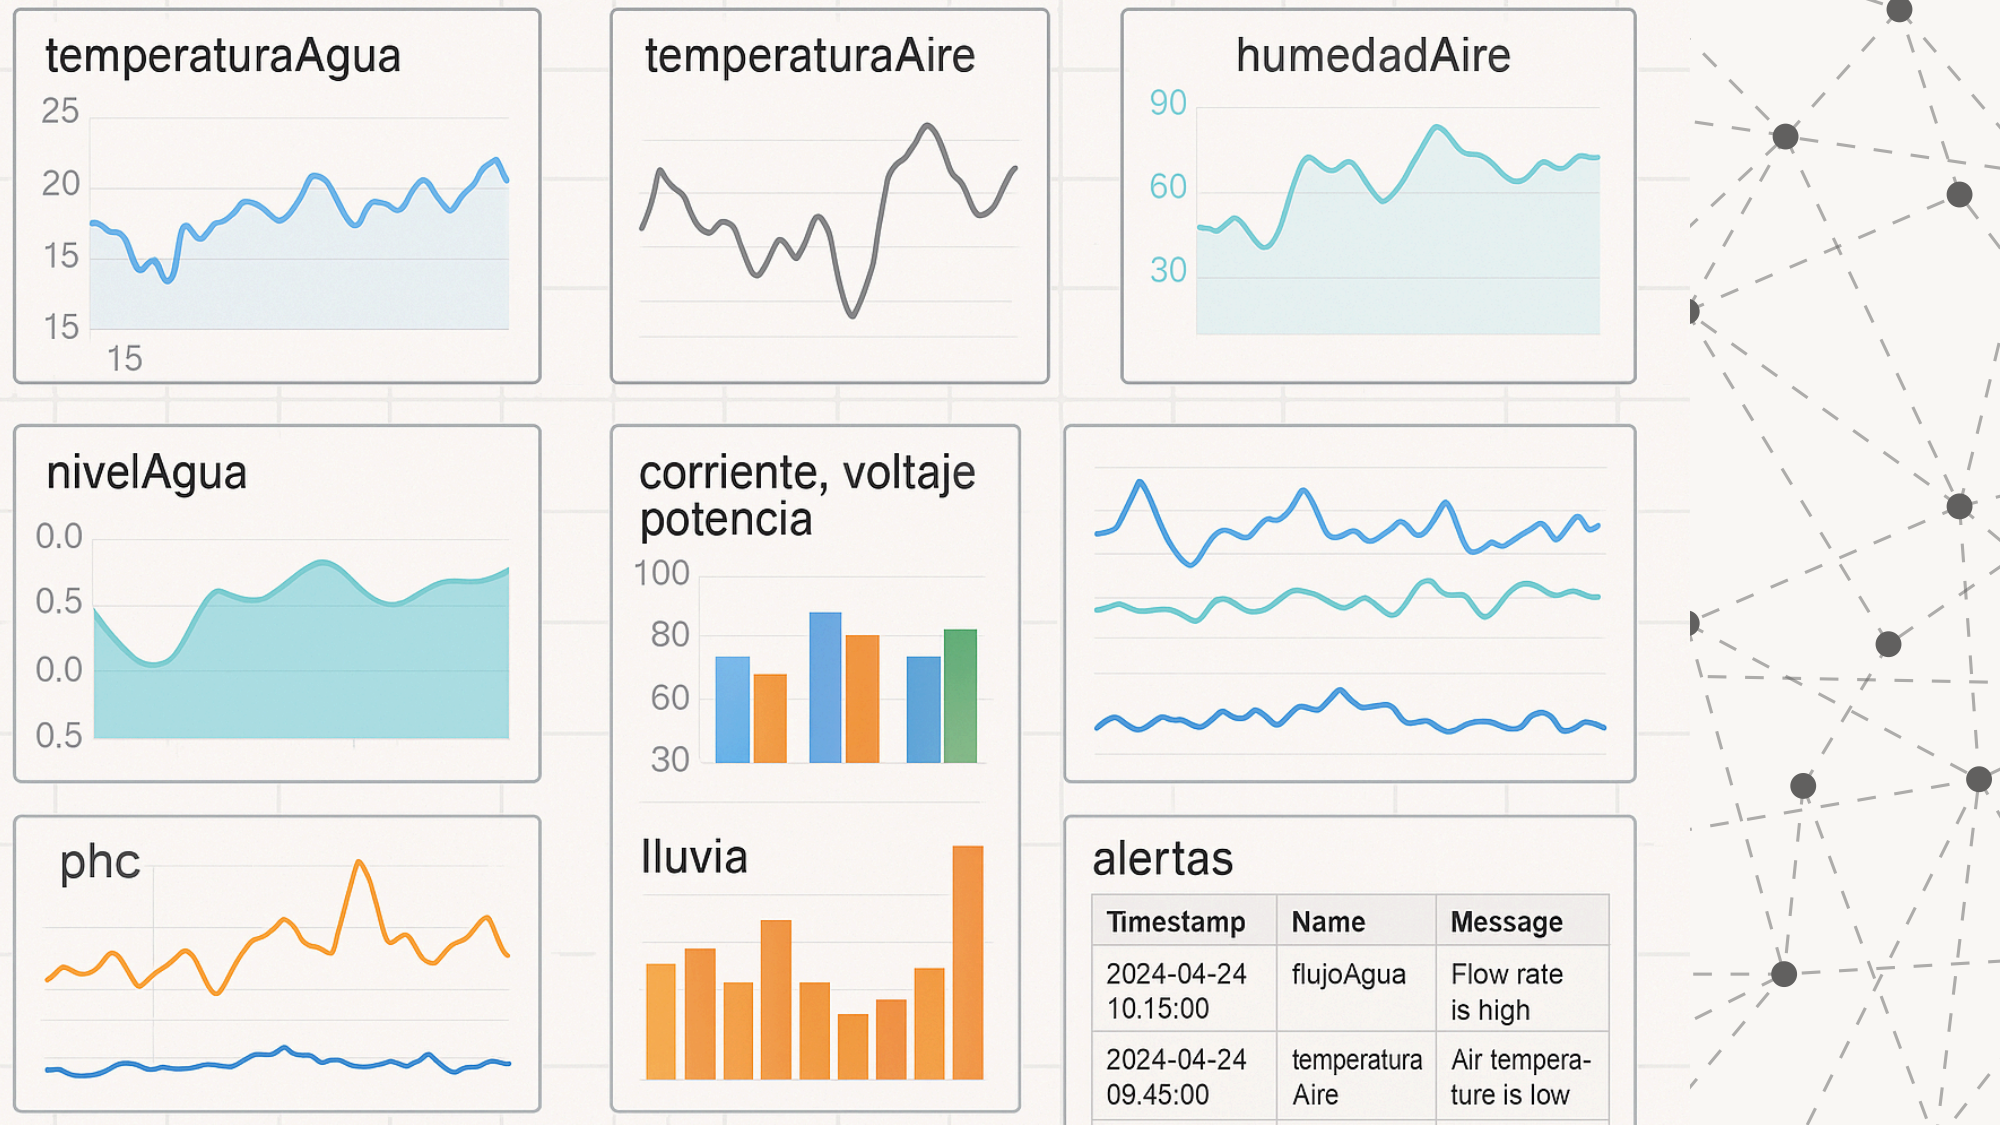
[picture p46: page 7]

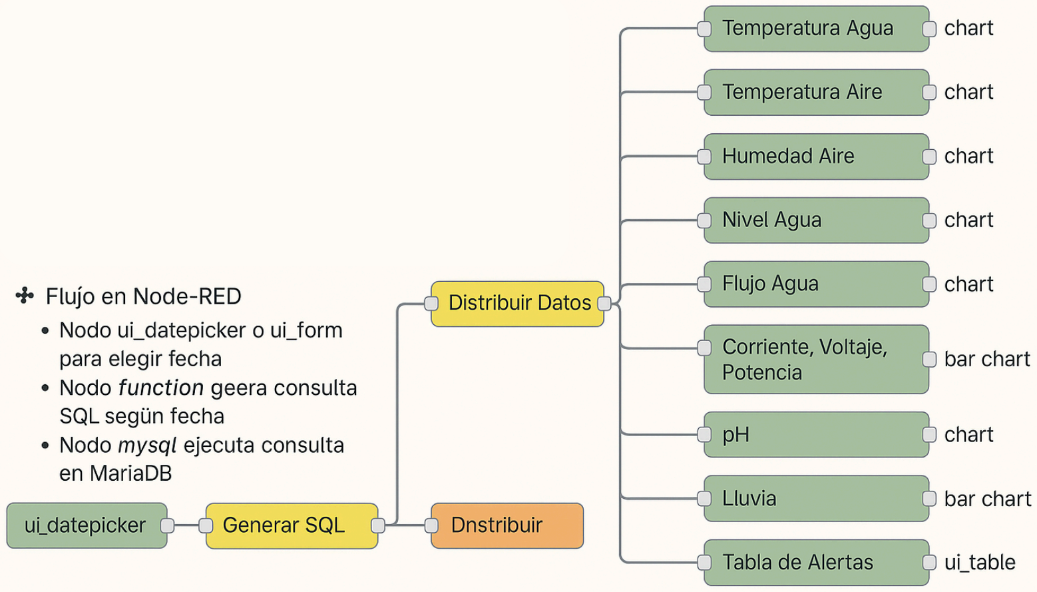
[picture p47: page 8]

# CONFIGURACIÓN Y AJUSTES

## Opciones de ajuste

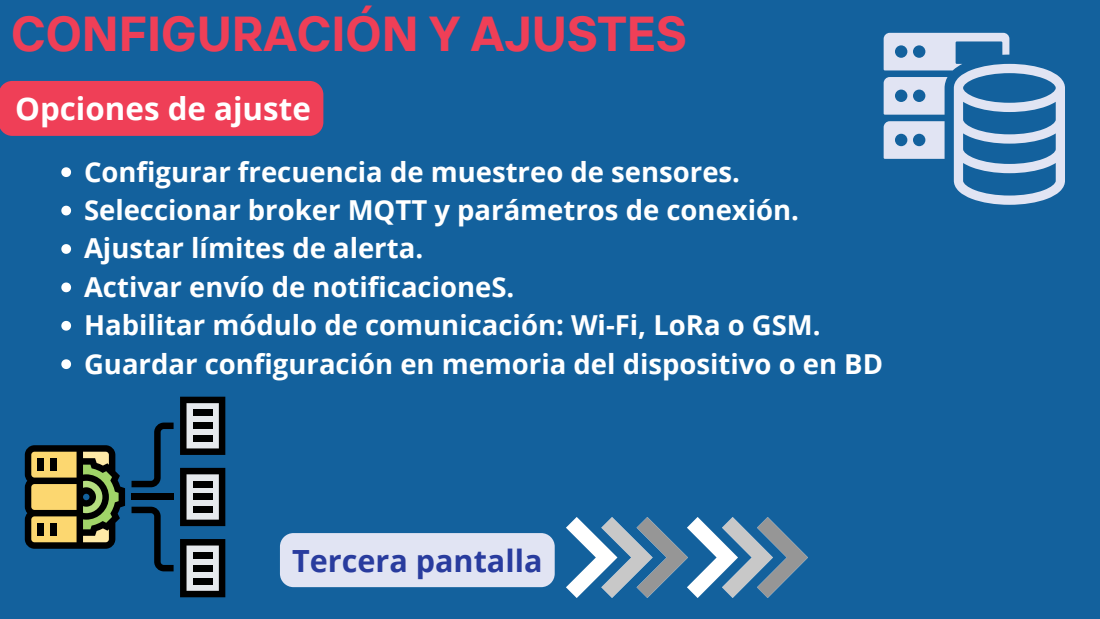
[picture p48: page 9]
Tercera pantalla

Configurar frecuencia de muestreo de sensores.
Seleccionar broker MQTT y parámetros de conexión.
Ajustar límites de alerta.
Activar envío de notificacioneS.
Habilitar módulo de comunicación: Wi-Fi, LoRa o GSM.
Guardar configuración en memoria del dispositivo o en BD

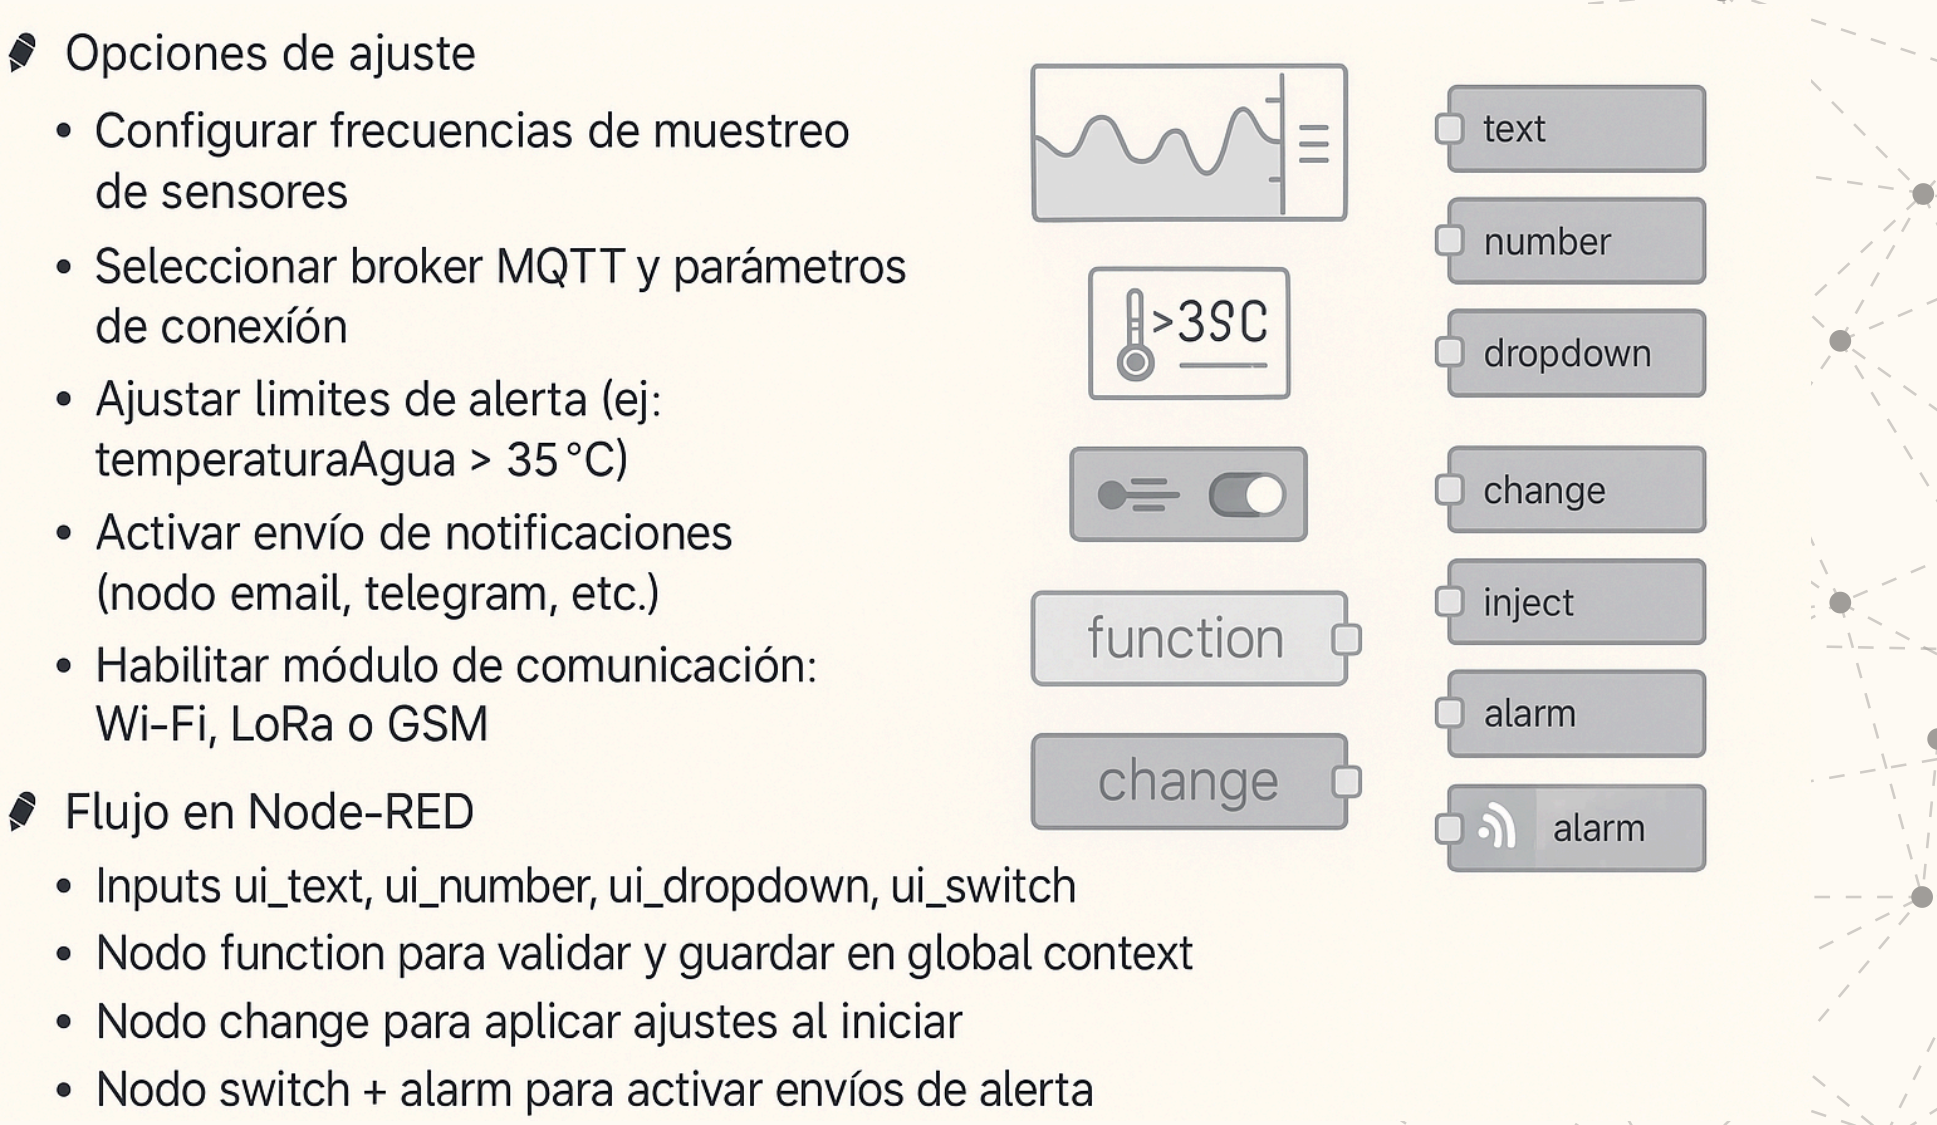
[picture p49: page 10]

# Configuración y ajustes

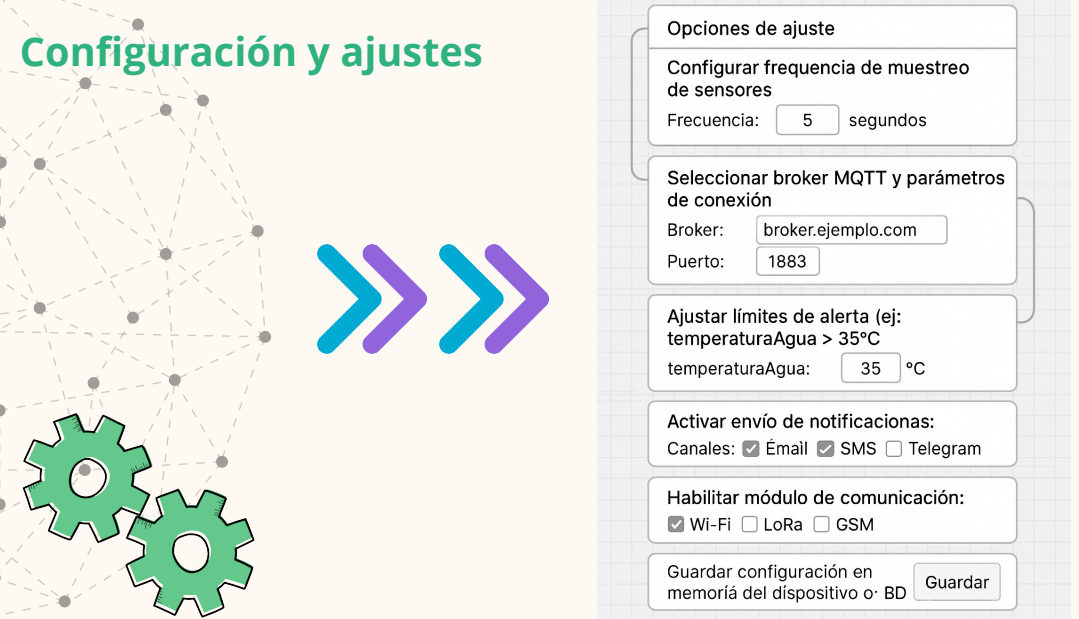
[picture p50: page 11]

### Última alerta registrada → Texto destacado

# ALERTAS Y MENSAJES DEL SISTEMA

Cuarta pantalla

Mensajes del sistema

Lista de alertas recientes → Tabla
Estado de conectividad (MQTT, Wi-Fi, LoRa, GSM) → LEDs o iconos
Estado del sistema (RTC, uptime, errores) → Texto dinámico
Logs → Área de texto con scroll

FIN

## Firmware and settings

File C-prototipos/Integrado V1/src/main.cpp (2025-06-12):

#include <Arduino.h>
#include <Preferences.h>
#include <Wire.h>
#include <ArduinoJson.h>
#include "SensorManager.h"
#include "ActuadorManager.h"
#include "CommunicationManager.h"
#include "ConfigHardware.h"

// --- Pines traidos desde ConfigHardware.h ---

// ANSI colors (para seriales compatibles como PlatformIO)
#define RED     "\033[31m"
#define GREEN   "\033[32m"
#define YELLOW  "\033[33m"
#define RESET   "\033[0m"

// --- Variables de configuración ---
String topicInfo, topicLectura, topicAlarma;
Preferences prefs;
String ssid, pass, broker, topic, deviceName, mqttUser, mqttPass;
uint16_t port;
uint32_t intervaloPublicacion = 60000; // Default: 1 min, modificable via pref.

// --- Instancias globales (como punteros) ---
CommunicationManager* commMgr = nullptr;
SensorManager* sensorMgr = nullptr;
ActuadorManager* actuadorMgr = nullptr;

// --- Estado para detectar cambios de alarma ---
int nivelAlarmaAnterior = 0;

// --- declaración de funciones ---
void enviarJsonCompuesto();
void enviarAlarma(int nivel);
void imprimirEstadoDispositivo();

// --- Función global para obtener ID corto del dispositivo ---
String idCorto() {
    uint64_t chipid = ESP.getEfuseMac();            // Obtiene el valor único de 64 bits
    char id[7];
    snprintf(id, sizeof(id), "%02X%02X%02X",        // Solo los últimos 3 bytes 
             (uint8_t)(chipid >> 16),
             (uint8_t)(chipid >> 8),
             (uint8_t)chipid);
    return String(id);
}

// ----------------------------------------------------
// ----------------------------------------------------
void cargarConfiguracion() {
    prefs.begin("config", true);
    ssid                 = prefs.getString("ssid", "");
    pass                 = prefs.getString("pass", "");
    broker               = prefs.getString("broker", "test.mosquitto.org");
    port                 = prefs.getUInt("port", 1883);
    deviceName           = prefs.getString("deviceName", "ESP32");
    intervaloPublicacion = prefs.getUInt("intervaloPublicacion", 60000);
    mqttUser             = prefs.getString("mqttUser", "");
    mqttPass             = prefs.getString("mqttPass", "");
    topicInfo            = prefs.getString("topicInfo", "info/default");
    topicLectura         = prefs.getString("topicLectura", "lecturas/default");
    topicAlarma          = prefs.getString("topicAlarma", "alarmas/default");

    umbralTempMax     = prefs.getFloat("umbralTempMax", 35.0);
    umbralHumMin      = prefs.getFloat("umbralHumMin", 30.0);
    umbralPresionMin  = prefs.getFloat("umbralPresionMin", 950.0);
    umbralLuxMin      = prefs.getFloat("umbralLuxMin", 200.0);
    umbralDistMax     = prefs.getFloat("umbralDistMax", 30.0);
    umbralCaudalMin   = prefs.getFloat("umbralCaudalMin", 1.0);
    umbralCO2Max      = prefs.getFloat("umbralCO2Max", 1000.0);
    umbralVoltMin     = prefs.getFloat("umbralVoltMin", 3.0);
    umbralCorrMin     = prefs.getFloat("umbralCorrMin", 0.05);
    prefs.end();
}

// -----------------------------------
// SETUP
// -----------------------------------
void setup() {
    Serial.begin(115200);
    void cargarConfiguracion();
    Wire.begin(PIN_I2C_SDA, PIN_I2C_SCL);

    // --- crear instancias de managers --- 
    commMgr = new CommunicationManager(
        Serial, Serial2, Serial1,
        ssid.c_str(), pass.c_str(),
        broker.c_str(), port,
        topicInfo.c_str(), topicLectura.c_str(), topicAlarma.c_str(),
        mqttUser.c_str(), mqttPass.c_str(),
        10000, 10000
    );

    sensorMgr = new SensorManager(
        PIN_I2C_SDA, PIN_I2C_SCL,
        PIN_DHT11,
        PIN_BH1750_SDA, PIN_BH1750_SCL,
        PIN_HCSR04_TRIG, PIN_HCSR04_ECHO,
        PIN_CAUDALIMETRO, FACTOR_CAUDAL,
        PIN_GAS
    );

    actuadorMgr = new ActuadorManager(
        PIN_BUZZER, PIN_RELE_BOMBA, PIN_LED_VERDE, PIN_LED_ROJO,
        *sensorMgr, *commMgr, topicAlarma.c_str()
    );

    // --- Inicializar managers ---
    sensorMgr->comenzar();
    actuadorMgr->comenzar();
    commMgr->begin();

    // --- setear estado inicial de alarma ---
    nivelAlarmaAnterior = actuadorMgr->getNivelAlarma();
    enviarInformacionDispositivo();
    Serial.println("[INFO] Setup completo.");
}

// -----------------------------------
// LOOP
// -----------------------------------
void loop() {
    static unsigned long lastPub = 0;

    sensorMgr->loop();
    actuadorMgr->loop();
    commMgr->loop();

    unsigned long now = millis();
    if (now - lastPub > intervaloPublicacion) {
        lastPub = now;
        enviarJsonCompuesto();
        imprimirEstadoDispositivo();
    }

    int nivelAlarmaActual = actuadorMgr->getNivelAlarma();
    if (nivelAlarmaActual != nivelAlarmaAnterior && nivelAlarmaActual != 0) {
        enviarAlarma(nivelAlarmaActual);
        nivelAlarmaAnterior = nivelAlarmaActual;
    }
}

// -----------------------------------
// Armado y envío del JSON compuesto por MQTT
// -----------------------------------
void enviarJsonCompuesto() {
    DynamicJsonDocument docFinal(1536);
    String sensoresStr = sensorMgr->obtenerJson();
    DynamicJsonDocument docSensores(1024);
    DeserializationError error = deserializeJson(docSensores, sensoresStr);

    if (error) {
        docFinal["device"] = deviceName;
        docFinal["id"]     = idCorto();
        docFinal["timestamp"] = millis();
        docFinal["sensores"]["error"] = "No data";
    } else {
        docFinal["timestamp"] = docSensores["timestamp"];
        docFinal["device"]    = deviceName;
        docFinal["sensores"]  = docSensores.as<JsonObject>();
        docFinal["sensores"].remove("timestamp");
    }

    JsonObject actuadores = docFinal["actuadores"].to<JsonObject>();
    actuadores["bomba"]  = actuadorMgr->isBombaEncendida();
    actuadores["alarma"] = actuadorMgr->getNivelAlarma();

    String payload;
    serializeJson(docFinal, payload);
    commMgr->publicar(topicLectura.c_str(), payload.c_str());

    Serial.println("[INFO] Payload publicado:");
    Serial.println(payload);
}

// -----------------------------------
// Envío inmediato de mensaje de alarma por MQTT
// -----------------------------------
void enviarAlarma(int nivel) {
    DynamicJsonDocument payload(256);
    payload["device"]  = deviceName;
    payload["id"]      = idCorto();
    payload["tipo"]    = "alarma";
    payload["nivel"]   = nivel;
    payload["origen"]  = actuadorMgr->getOrigenAlarma();
    switch (nivel) {
        case 3: payload["mensaje"] = "Alarma CRITICA"; break;
        case 2: payload["mensaje"] = "Alarma MEDIA";   break;
        case 1: payload["mensaje"] = "Alarma BAJA";    break;
        default: payload["mensaje"] = "Alarma desconocida"; break;
    }
    String out;
    serializeJson(payload, out);
    commMgr->publicar(topicAlarma.c_str(), out.c_str());
    Serial.println("[INFO] Alarma publicada:");
    Serial.println(out);
}

// -----------------------------------

void enviarInformacionDispositivo() {
    DynamicJsonDocument doc(2048);
    doc["device"] = deviceName;
    doc["id"]     = idCorto();
    doc["evento"] = "inicio";

    JsonArray sensores = doc.createNestedArray("sensores");

    JsonObject dht = sensores.createNestedObject();
    dht["nombre"] = "DHT11";
    dht["pin"] = PIN_DHT11;
    dht["umbralTempMax"] = prefs.getFloat("umbralTempMax", 35.0);
    dht["umbralHumMin"] = prefs.getFloat("umbralHumMin", 30.0);

    JsonObject bmp = sensores.createNestedObject();
    bmp["nombre"] = "BMP280";
    bmp["pin"] = -1;
    bmp["umbralPresionMin"] = prefs.getFloat("umbralPresionMin", 950.0);

    JsonObject bh = sensores.createNestedObject();
    bh["nombre"] = "BH1750";
    bh["pin"] = PIN_BH1750_SDA;
    bh["umbralLuxMin"] = prefs.getFloat("umbralLuxMin", 200.0);

    JsonObject sr = sensores.createNestedObject();
    sr["nombre"] = "HC-SR04";
    sr["pinTrig"] = PIN_HCSR04_TRIG;
    sr["pinEcho"] = PIN_HCSR04_ECHO;
    sr["umbralDistMax"] = prefs.getFloat("umbralDistMax", 30.0);

    JsonObject caudal = sensores.createNestedObject();
    caudal["nombre"] = "Caudalimetro";
    caudal["pin"] = PIN_CAUDALIMETRO;
    caudal["umbralCaudalMin"] = prefs.getFloat("umbralCaudalMin", 1.0);

    JsonObject co2 = sensores.createNestedObject();
    co2["nombre"] = "CO2";
    co2["pin"] = PIN_CO2;
    co2["umbralCO2Max"] = prefs.getFloat("umbralCO2Max", 1000.0);

    JsonObject energia = sensores.createNestedObject();
    energia["nombre"] = "Energia";
    energia["pin"] = PIN_ENERGIA;
    energia["umbralVoltMin"] = prefs.getFloat("umbralVoltMin", 3.0);
    energia["umbralCorrMin"] = prefs.getFloat("umbralCorrMin", 0.05);

    JsonArray actuadores = doc.createNestedArray("actuadores");

    JsonObject bomba = actuadores.createNestedObject();
    bomba["nombre"] = "BOMBA";
    bomba["pin"] = PIN_RELE_BOMBA;
    bomba["estado"] = actuadorMgr->isBombaEncendida() ? "ON" : "OFF";

    JsonObject buzzer = actuadores.createNestedObject();
    buzzer["nombre"] = "BUZZER";
    buzzer["pin"] = PIN_BUZZER;

    JsonObject ledV = actuadores.createNestedObject();
    ledV["nombre"] = "LED_VERDE";
    ledV["pin"] = PIN_LED_VERDE;

    JsonObject ledR = actuadores.createNestedObject();
    ledR["nombre"] = "LED_ROJO";
    ledR["pin"] = PIN_LED_ROJO;

    String out;
    serializeJson(doc, out);
    commMgr->publicar(topicInfo.c_str(), out.c_str());

    Serial.println("[INFO] Mensaje de inicio publicado:");
    Serial.println(out);
}

// -----------------------------------
void imprimirEstadoDispositivo() {
    Serial.println(YELLOW "\n========= ESTADO DEL DISPOSITIVO =========" RESET);

    String jsonSensores = sensorMgr->obtenerJson();
    DynamicJsonDocument doc(1024);
    deserializeJson(doc, jsonSensores);

    const char* sensores[] = { "BMP280", "DHT11", "BH1750", "HC-SR04", "Caudal", "CO2", "Energia" };
    for (const char* s : sensores) {
        const char* estado = doc[s]["estado"] | "desconocido";
        const char* color  = strcmp(estado, "OK") == 0 ? GREEN : RED;
        Serial.printf("%s[SENSOR]  %-9s: %s%s\n", color, s, estado, RESET);
    }

    Serial.printf("%s[ACTUADOR] Bomba      : %s%s\n", 
        actuadorMgr->isBombaEncendida() ? GREEN : RED,
        actuadorMgr->isBombaEncendida() ? "ON" : "OFF",
        RESET);

    Serial.printf("%s[ACTUADOR] Alarma     : Nivel %d%s\n", 
        actuadorMgr->getNivelAlarma() > 0 ? RED : GREEN,
        actuadorMgr->getNivelAlarma(),
        RESET);

    Serial.printf("%s[COMMS]    Wi-Fi      : %s%s\n",
        commMgr->redHabilitada() ? GREEN : RED,
        commMgr->redHabilitada() ? "CONECTADO" : "DESCONECTADO",
        RESET);

    // MQTT y GSM son privados → podés expandir CommunicationManager con funciones públicas si querés:
    // Por ahora asumimos solo `redHabilitada()` como resumen de ambos.

    Serial.println(YELLOW "============================================\n" RESET);
    }

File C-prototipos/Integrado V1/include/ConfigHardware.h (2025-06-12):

// ConfigHardware.h
#pragma once

// Sensores analógicos
#define PIN_LM35           36
#define PIN_PH             34
#define PIN_EC             35
#define PIN_CORRIENTE      32
#define PIN_GAS            39

// Sensores digitales
#define PIN_DHT11          4
#define PIN_DS18B20        5
#define PIN_FLOTADOR       14
#define PIN_HCSR04_TRIG    12
#define PIN_HCSR04_ECHO    13
#define PIN_RELE_BOMBA     25
#define PIN_CAUDALIMETRO   26
#define PIN_ENERGIA        33
#define PIN_BUZZER         27
#define PIN_LLUVIA         18

// Sensores I2C
#define PIN_I2C_SDA        21
#define PIN_I2C_SCL        22
#define PIN_BH1750_SDA     PIN_I2C_SDA
#define PIN_BH1750_SCL     PIN_I2C_SCL
#define PIN_BME280_SDA     PIN_I2C_SDA
#define PIN_BME280_SCL     PIN_I2C_SCL
#define PIN_RTC_SDA        PIN_I2C_SDA
#define PIN_RTC_SCL        PIN_I2C_SCL

#define PIN_LED_VERDE      2
#define PIN_LED_ROJO       15

// Constantes generales
#define FACTOR_CAUDAL      450.0f
#define PIN_CO2            19  

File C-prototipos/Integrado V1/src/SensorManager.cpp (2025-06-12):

#include "SensorManager.h"
#include <Arduino.h>
#include <Wire.h>
#include <ArduinoJson.h>
#include <ConfigHardware.h>

//----------------------------------
// Funciones auxiliares para caudalímetro
//----------------------------------
static float calcularCaudal(int pulsos, float factorPulsosPorLitro, float intervaloSeg) {   // factorPulsosPorLitro: p.ej. 450 pulsos/L
  return ( (float)pulsos / factorPulsosPorLitro ) * (60.0f / intervaloSeg);                 // caudal (L/min) = (pulsos / factor) * (60 / intervaloSeg)
}
static float calcularVolumen(int pulsos, float factorPulsosPorLitro) {                      // volumen (L) = pulsos / factor
  return (float)pulsos / factorPulsosPorLitro;
}

//------------------------------
// Constructor
//------------------------------
SensorManager::SensorManager(
    uint8_t i2c_sda, uint8_t i2c_scl,
    uint8_t pin_dht11,
    uint8_t pin_bh1750_sda, uint8_t pin_bh1750_scl,
    uint8_t pin_sr04_trig, uint8_t pin_sr04_echo,
    uint8_t pin_caudalimetro, float factor_caudal,
    uint8_t pin_co2
)
  : bmp_(PIN_I2C_SDA, PIN_I2C_SCL)                        // Ahora acepta pines I2C
  , dht_(PIN_DHT11)                                       // DHT11 con pin
  , bh1750_(PIN_BH1750_SDA, PIN_BH1750_SCL)               // BH1750 con I2C configurable
  , sr04_()                                               // Pines en el constructor
  , caudalimetro_(PIN_CAUDALIMETRO, FACTOR_CAUDAL)        // Caudalímetro parametrizado
  , rtc_()                                                // RTC usa Wire por defecto, pines por begin()
  , co2_(PIN_CO2)                                         // Sensor CO2 con pin configurable
  , moduloEnergia_(Wire)                                  // Módulo energía acepta Wire

  // Valores arbitrarios iniciales; luego se sobrescriben con NVS
  , tempBMP_(NAN)
  , presionBMP_(NAN)
  , alturaBMP_(NAN)
  , tempDHT_(NAN)
  , humDHT_(NAN)
  , luxBH_(NAN)
  , distSR_(NAN)
  , pulsosCapturados_(0)
  , caudal_(NAN)
  , volumenAcum_(NAN)
  , horaRTC_("desconocida")
  , co2PPM_(NAN)
  , voltaje_(NAN)
  , corriente_(NAN)
  , potencia_(NAN)
  
  // Umbrales por defecto
  , umbralTempMax_(40.0f)
  , umbralHumMin_(30.0f)
  , umbralPresionMin_(980.0f)
  , umbralLuxMin_(100.0f)
  , umbralDistMax_(200.0f)
  , umbralCaudalMin_(0.5f)
  , umbralCO2Max_(1000.0f)
  , umbralVoltMin_(3.0f)
  , umbralCorrMin_(0.1f)
  , intervaloLecturaMs_(5000)
  , ultimaLecturaMs_(0)
  , estado_(Estado::Inactivo)
{
}

//------------------------------
// comenzar(): inicializa todo
//------------------------------
void SensorManager::comenzar() {
  // 1) Cargar umbrales e intervalo desde NVS
  prefs_.begin("config", true);
  umbralTempMax_     = prefs_.getFloat("umbralTempMax",     umbralTempMax_);
  umbralHumMin_      = prefs_.getFloat("umbralHumMin",      umbralHumMin_);
  umbralPresionMin_  = prefs_.getFloat("umbralPresionMin",  umbralPresionMin_);
  umbralLuxMin_      = prefs_.getFloat("umbralLuxMin",      umbralLuxMin_);
  umbralDistMax_     = prefs_.getFloat("umbralDistMax",     umbralDistMax_);
  umbralCaudalMin_   = prefs_.getFloat("umbralCaudalMin",   umbralCaudalMin_);
  umbralCO2Max_      = prefs_.getFloat("umbralCO2Max",      umbralCO2Max_);
  umbralVoltMin_     = prefs_.getFloat("umbralVoltMin",     umbralVoltMin_);
  umbralCorrMin_     = prefs_.getFloat("umbralCorrMin",     umbralCorrMin_);
  intervaloLecturaMs_= prefs_.getUInt("intervaloSensoresMs", intervaloLecturaMs_);
  float factorCalib  = prefs_.getFloat("factorCaudal", 450.0f);

  prefs_.end();

  // 2) Inicializar cada sensor; si alguno falla críticamente, pasa a Estado::Error
  Wire.begin(); // [I2C genérico] Inicializamos Wire para BMP280, BH1750, Módulo de Energía, RTC

  // 2.2) BMP280
  if (!bmp_.begin()) {
    Serial.println("[SensorMgr] [ERROR] no pudo inicializar BMP280");
    estado_ = Estado::Error;
    return;
  }

  // 2.3) DHT11
  dht_.begin(); // no devuelve error; lecturas posteriores detectan NAN

  // 2.4) BH1750
  if (!bh1750_.begin()) {
    Serial.println("[SensorMgr] [ERROR] no pudo inicializar BH1750");
    estado_ = Estado::Error;
    return;
  }

  // 2.5) HC-SR04 (pines definidos en el constructor)
  sr04_.begin(PIN_HCSR04_TRIG, PIN_HCSR04_ECHO);

  // 2.6) Caudalímetro (no requiere begin; simplemente usar ISR y setPulsosCaudal)

  // 2.7) RTC DS3231
  rtc_.begin(); // si no arranca, getTimeString detecta fallo luego

  // 2.8) SensorCO2
  co2_.begin(); // imprime calibración en Serial; siempre debería completar

  // 2.9) Módulo de Energía
  moduloEnergia_.begin();
  if (!moduloEnergia_.isCommunicationOK()) {
    Serial.println("[SensorMgr] [ERROR] no pudo comunicarse con Módulo de Energía");
    estado_ = Estado::Error;
    return;
  }

  // Si llegamos aquí, todo OK → pasamos a Estado::Leyendo
  estado_ = Estado::Leyendo;
  ultimaLecturaMs_ = millis();
  Serial.println("[SensorMgr] [INFO] Sensores inicializados correctamente");
}

//------------------------------
// loop(): lee cuando toca
//------------------------------
void SensorManager::loop() {
  if (estado_ != Estado::Leyendo) return;

  unsigned long ahora = millis();
  if (ahora - ultimaLecturaMs_ < intervaloLecturaMs_) {
    return; // aún no toca leer
  }
  ultimaLecturaMs_ = ahora;

  leerSensores();
}
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

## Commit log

2025-04-23 se crea la estructura del repositorio
2025-04-24 Se suben pruebas unitarias de buzzer y sr04
2025-04-24 Agrego manual flujo de trabajo para el equipo
2025-04-25 pruebas unitarias sensor DHT11
2025-04-25 Emma-Subi Documentación de Prueba Sensor de Gas para Proyecto_hidroponico
2025-04-25 EMMA-Prueba de SensorGas_IoT con Mq2
2025-04-25 se agrega contenido de sensor para CO2
2025-04-25 Update ManualFlujodeTrabajoEquipo.md
    Se corrige nombre de rama Develop por Development para evitar confusiones
2025-04-25 Se carga prueba unitaria mq2
    Se carga la preuba unitaria del sensor MQ2 simulando a un sensor de CO2
2025-04-26 Se sube Pruebas Unitarias del Sensor de Temperatura DS18B20
2025-04-26 prueba unitaria MQ2 para CO2
2025-04-26 Se crea pruebaa unittaria sensor GY302
2025-04-26 Test Unitario Bomba de Agua Control
2025-04-26 Consumo de Energia
    Subo la carpeta de "Consumo de Energía"
2025-04-28 se realiza prueba en wokwi sensor TDS
2025-04-28 Create SENSOR DE LLUVIA-WOKWI
2025-04-28 se agrega contenido sensor tds
2025-04-29 Agregar pruebas unitarias del sensor de lluvia
2025-04-29 Actualización del README.md y prueba unitaria
    Actualizo el archivo README.md agregando los pasos para ejecutar las pruebas unitarias
2025-04-29 Correcion de codigo en la función test_adquisicion_datos()
    La función test_adquisicion_datos() llamaba a analogRead(sensorPin) dos veces (en las líneas 23 y 24), lo que podía generar lecturas inconsistentes del sensor si el valor analógico cambia entre llama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
2025-04-30 Actualizacion de branch Se mejora significativamente el manua Se modifica la estructura del clase para instanciarlo como clase (sr04)
2025-04-30 Actualizacion de branch Actualizacion del codigo de buzzer, Utiliznaod clases, y mejorando significativamente el manual de uso
    [main.cpp]
2025-04-30 Actualizacion de buzzer/main. Se corrige gestion de ingreso de mensajes por consola (trigger de alarma)
    [main.cpp]
2025-04-30 Correccion buzzer.h - Se corrige caracteristica del param que genereaba errores en la complilacion
2025-05-08 Add DS Esp32 dev Kit + LCD 20*4
2025-05-08 Add image ESP32 DevKit 30p
2025-05-09 Cambio de sensor (YF-401) e implementación RISING
2025-05-10 Add files via upload
    Se gragan cambios sobre gestion de MQ2 con lectura analogica, lectura general utilizando libreria [miguel5612/MQUnifiedsensor@^3.0.0] que nos facilita la manera el que hacemos la calibracion.
    Documentacion de la libreria https://github.com/miguel5612/MQSensorsLib
    Se comprueba compilacion correcta + prueba en dispositivio fisico danto lecturas (erraticas debido a falta de precalentamiento del sensor de 10-24hs)
    [SensorCO2.cpp, SensorCO2.h, main.cpp]
2025-05-10 Add files via upload
    A considerar, y no menor. El MQ2 -NO ESTA DISEÑADO PARA MEDIR CO2-
    Pero si sensores como el MQ-135. La libreria permite gesitonar varios sensores de la flia MQ sin mucho problema.
    Se tiene que descomentar 2 lineas que deje indicadas en .h y .cpp
    - .h (../include\SensorCO2.h)
    --- linea 22: #define RATIO_CLEAN_AIR 3.8f
    --- linea 23: #define RL_KOHM 20.0f
    - .cpp (../include\SensorCO2.h)(../include\SensorCO2.cpp)
    --- linea 7: , mq(BOARD, VCC, ADC_RES, sensorPin, F("MQ-135")) {}
    [SensorCO2.cpp, SensorCO2.h, main.cpp]
2025-05-10 Add files via upload
    Se agrega datasheets MQ-2 y MQ-135. + Manual de uso del la prueba.
2025-05-13 Documentar Variables de Medicion #39
2025-05-15 Actualizo pruebas unitarias y subo documentos de diseño de prototipo
    [Bomba.FCStd, Caudalimetro.FCStd, Modelo_final.FCStd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]
2025-05-16 Cambio de organizacion de directorio
2025-05-18 actualizo integracion sensor bmp280 + RTC + JASON con conexion mqtt
2025-05-19 Se crea la estructura del integrador, con manual y descripciones.
2025-05-19 Se crean las librerias de Wifi y GSM. Queda por corregir y definir funciones manuales
2025-05-29 Carga de API-MQTT listener
    Carga de API-MQTT listener para ingreso de datos en DB. Queda pendiente corregir parseo de datos para adaptarse a la DB final
2025-05-30 Se sube Carpeta de Documentación Proyecto_Hidroponía ISPC_Integrado_2025_Documentación
2025-05-30 Se sube en la carpeta Documentación de Investigación la Ducumentación Técnica del Proyecto Hipónico
2025-06-02 se realiza readme de base de datos
2025-06-03 Implementación completa del módulo de medición de energía con pruebas unitarias y mock de I2C
    Se agrega el módulo Modulo_de_Energia para medición de voltaje, corriente y potencia vía I2C.
    Se incluye el código fuente principal para ESP32-S3 (main.cpp) y la configuración de PlatformIO.
    Se implementan pruebas unitarias exhaustivas usando Unity en la carpeta test/, con simulación de bus I2C mediante MockWire.
    Se documenta la estructura, instrucciones de uso y resultados de pruebas en los archivos README y Resultados.md.
    Preparado para ejecución en hardware real y simulación en Wokwi.
2025-06-04 se modifica base de datos
2025-06-04 Comig de carga
2025-06-04 Actualizacion de connection manager. Ahora despliega correctamente coneccion con portal web de ESP32 para colocacion de credenciales. Se comprueba funcionamiento en fisico
    [CommunicationManager.cpp]
2025-06-05 se conecta base de datos a grafana y node-red
2025-06-05 Actualizacion de integracion. Se integran los 3 posible manager. Complia OK, pero parece un error en la dependencias del .ini. Se contiuna revisando
    [CommunicationManager.cpp, SensorManager.cpp, main.cpp]
2025-06-06 Actualizacion de logica de envio via MQTT con json, para centralizarla en main
2025-06-06 Correccion de error con libreria Wire faltante en modulo energia, funcion no declada en wifi.cpp y faltante de un valor asociado a la config I2C del BH1750
    [main.cpp]
2025-06-07 Actualizacion de error buzzer
2025-06-07 Actualizaciones en API para gestion de la fata mandada. Se configura tipicos, y division de datos pra acomplar con diagrama de la base de datos. De momento no se realizan pruebas de envio
2025-06-09 Se sube el documento Inteligencia Artificial en el Proyecto Hidropónico ISPC en la Carpeta de Documentación de Investigación del Proyecto Hidropónico ISPC
2025-06-09 Documento ABP
    Subo el documento ABP correspondiente al Proyecto Hidroponico de la Materia Proyecto Integrador 2 de la carrera de Telecomunicaciones del ISPC
2025-06-12 Correccion ENV listo para despliegue en servidor externo
2025-06-12 contiene una biblioteca de sensores de luz dijitales BH1750
2025-06-13 Correccion menor en mensaje que generaba error cuando un valor de control venia vacio
    [mensaje.py]
2025-06-13 README actualizado y una guía de instalación mínima
2025-06-13 Version final. COmmit para asegurar ultimo estado en carpeta final
2025-06-14 Actualizacion, correccion ante valoes PIN null
2025-06-14 Actualizacion: Problema con el registro de luces cuando y bomba cuando cambiaba de valor. Problema en el parseo
    [SimuladorIngresoEspecifico.py]
2025-06-16 se documenta sobre el uso de grafana
2025-06-18 Se agrega data sheet DS1307 RTC i2c
2025-06-18 se agrega datasheet ultrasonico HC-SR04
2025-06-18 Se agrego imagen de grafana
2025-06-18 Add files via upload
    Agrego hojas de datos de sensores usados en el proyecto
2025-06-18 se agrega manual de usuario
2025-06-18 se agrega datasheet sensor TDS
2025-06-18 Actualizacion | Carga de arquitectura de red
